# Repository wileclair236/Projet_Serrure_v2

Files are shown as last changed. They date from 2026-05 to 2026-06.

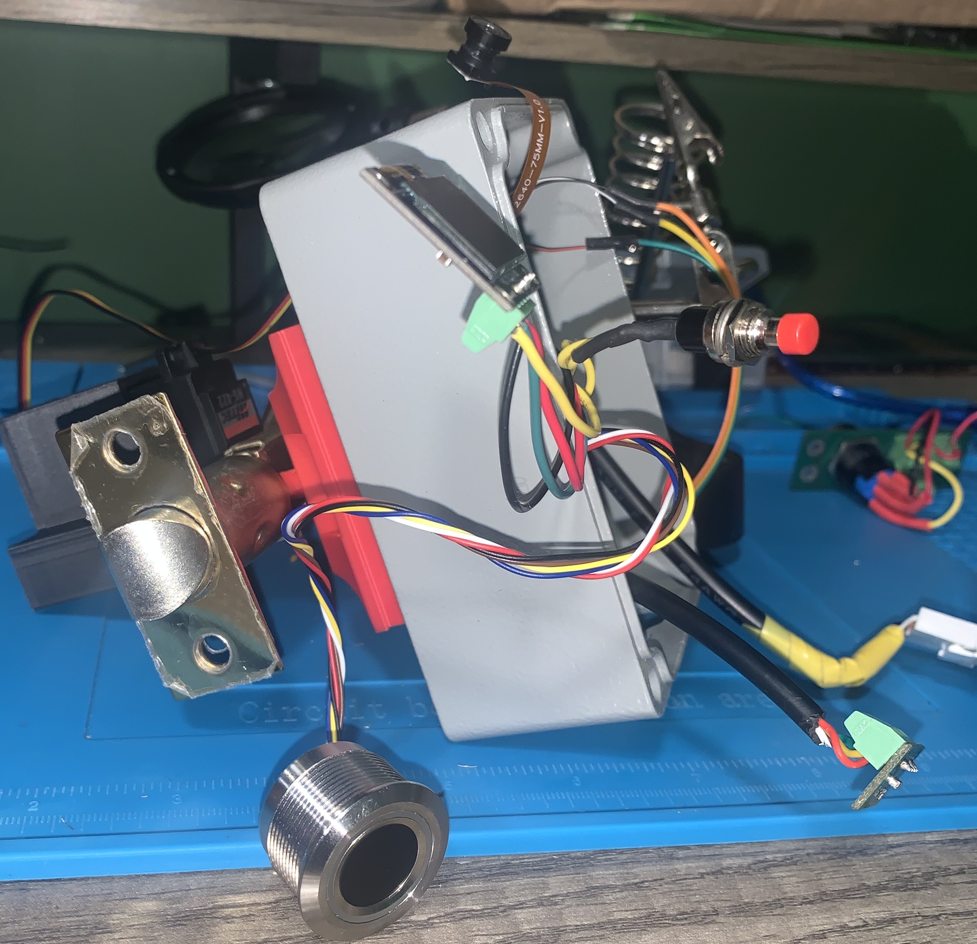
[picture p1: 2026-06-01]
Images/image site_web/IMG_6027.jpeg

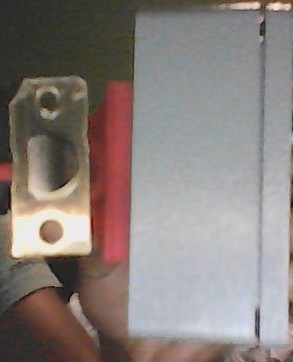
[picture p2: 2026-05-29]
Images/image site_web/photo serrure 2.jpg

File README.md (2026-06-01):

# Serrure Intelligente Connectée

## Description

Ce projet consiste en la conception et la réalisation d'une serrure intelligente connectée permettant le contrôle d'accès d'une porte à l'aide de plusieurs méthodes d'authentification. La serrure peut être commandée localement ou à distance via Home Assistant.

Le système est composé de plusieurs circuits imprimés (PCB) assurant la gestion des accès, les communications sans fil, l'acquisition d'images, le stockage des événements et le contrôle du mécanisme de verrouillage.

## Fonctionnalités

* Déverrouillage par carte RFID
* Déverrouillage par empreinte digitale
* Déverrouillage à distance via Home Assistant
* Déverrouillage mécanique par clé
* Notifications en temps réel
* Capture d'images lors des événements d'accès
* Journalisation des accès
* Gestion de plusieurs utilisateurs
* Contrôle d'un servomoteur pour le verrouillage et le déverrouillage
* Communication sans fil via Wi-Fi et MQTT

## Architecture du système

### PCB principal

Le PCB principal assure le contrôle complet de la serrure :

* Gestion des communications avec Home Assistant
* Gestion des utilisateurs autorisés
* Traitement des demandes d'accès
* Contrôle du servomoteur
* Acquisition et stockage des données
* Gestion des capteurs et périphériques

### PCB de la clé mécanique

Le PCB secondaire agit comme un interrupteur relié au PCB principal. Lorsqu'une clé est insérée puis tournée, il transmet un signal d'ouverture au contrôleur principal afin de permettre l'accès.

## Matériel utilisé

* ESP32-S3
* Lecteur RFID MFRC522
* Capteur d'empreintes digitales R503
* Caméra OV2640
* Écran OLED
* Servomoteur
* Carte microSD
* Capteur de proximité Vcnl36825t
* Batterie AA

## Logiciels utilisés

* PlatformIO
* Home Assistant
* MQTT
* Git
* KiCad

## Communication MQTT

Le système utilise MQTT pour transmettre les informations entre la serrure et Home Assistant.

## Sécurité

* Gestion des utilisateurs autorisés
* Journalisation des accès
* Authentification par plusieurs méthodes
* Surveillance des événements en temps réel
* Notifications automatiques vers Home Assistant

## Résultats

La serrure permet un contrôle d'accès sécurisé et connecté tout en conservant une solution de secours mécanique grâce à la clé physique. L'intégration avec Home Assistant offre une supervision en temps réel ainsi qu'une gestion centralisée des accès.

## Auteur

Wilkens Pinthière
Projet de conception d'une serrure intelligente connectée.

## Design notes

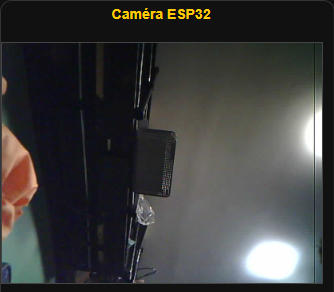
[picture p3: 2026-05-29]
Images/image site_web/stream.png

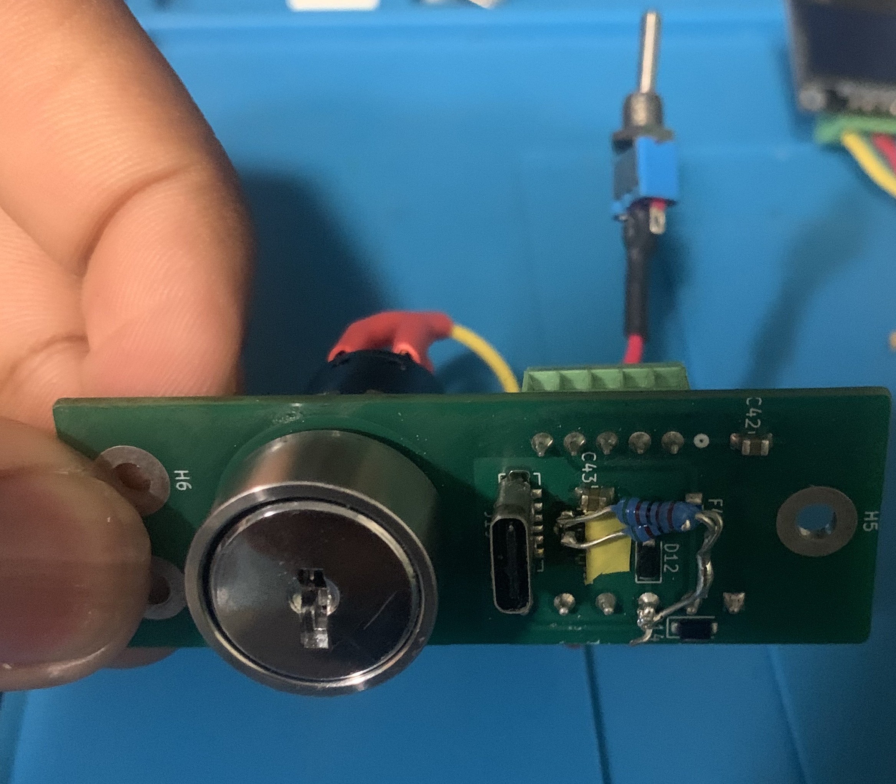
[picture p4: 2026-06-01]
Images/image site_web/Image PCB cle.jpeg

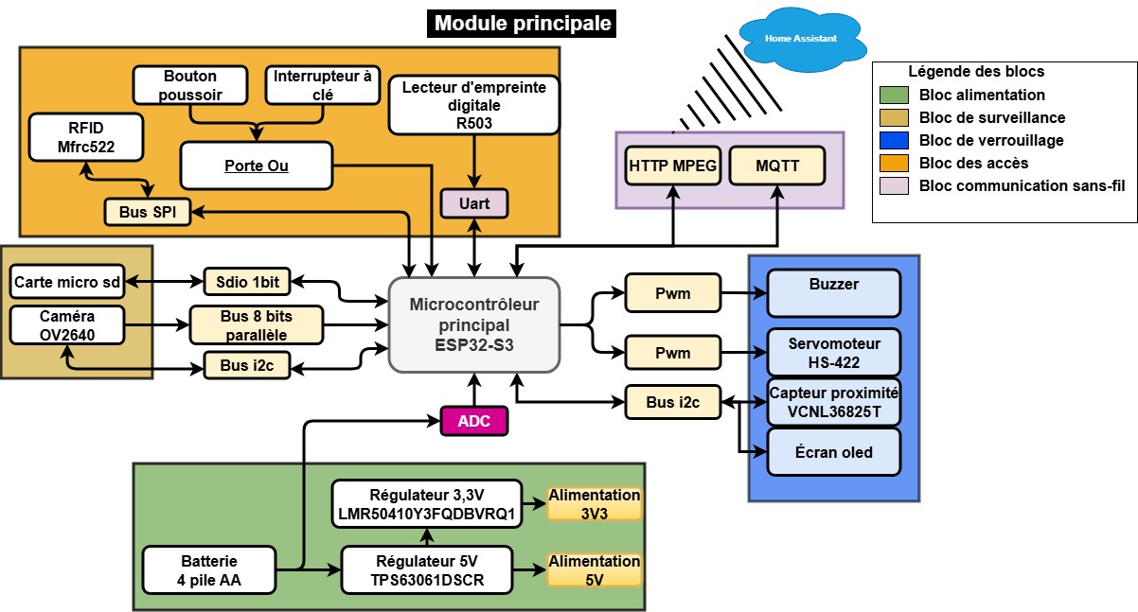
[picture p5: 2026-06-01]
Images/image site_web/Schema de principle.jpg

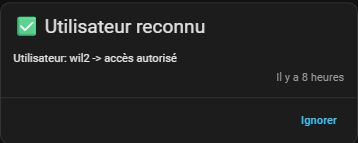
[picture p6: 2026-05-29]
Images/image site_web/HA_3.png

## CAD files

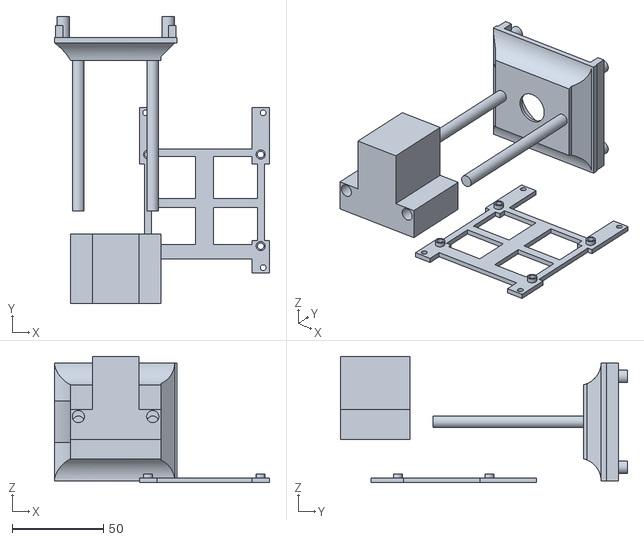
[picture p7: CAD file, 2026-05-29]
Fichier CAD/Fusion/impression 1.stl
118.1 x 157.5 x 69.2

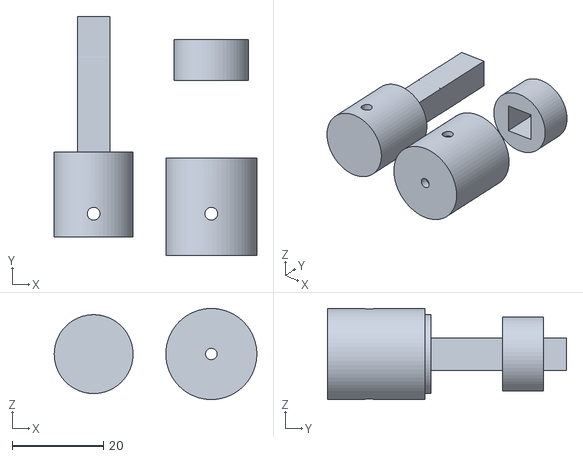
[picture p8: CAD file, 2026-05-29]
Fichier CAD/Fusion/impression 2.stl
44.4 x 52.3 x 19.9

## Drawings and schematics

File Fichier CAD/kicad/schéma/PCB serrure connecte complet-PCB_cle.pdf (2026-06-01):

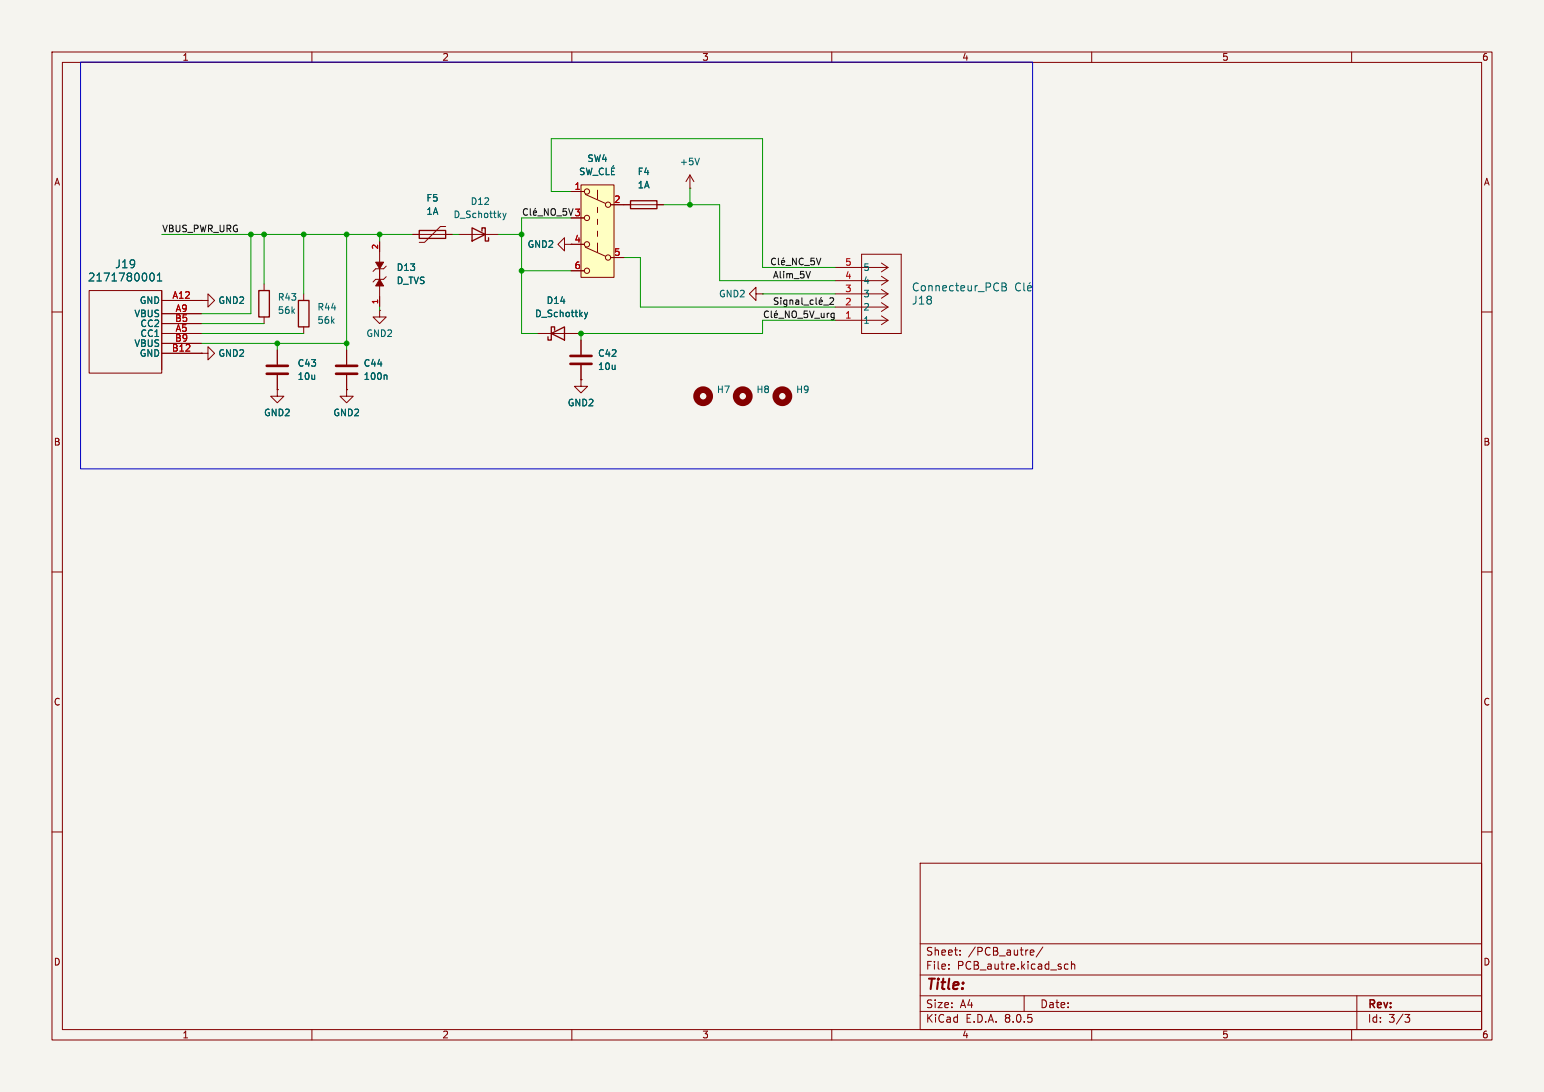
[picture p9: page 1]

Id: 3/3 Title: File: PCB_autre.kicad_sch Sheet: /PCB_autre/

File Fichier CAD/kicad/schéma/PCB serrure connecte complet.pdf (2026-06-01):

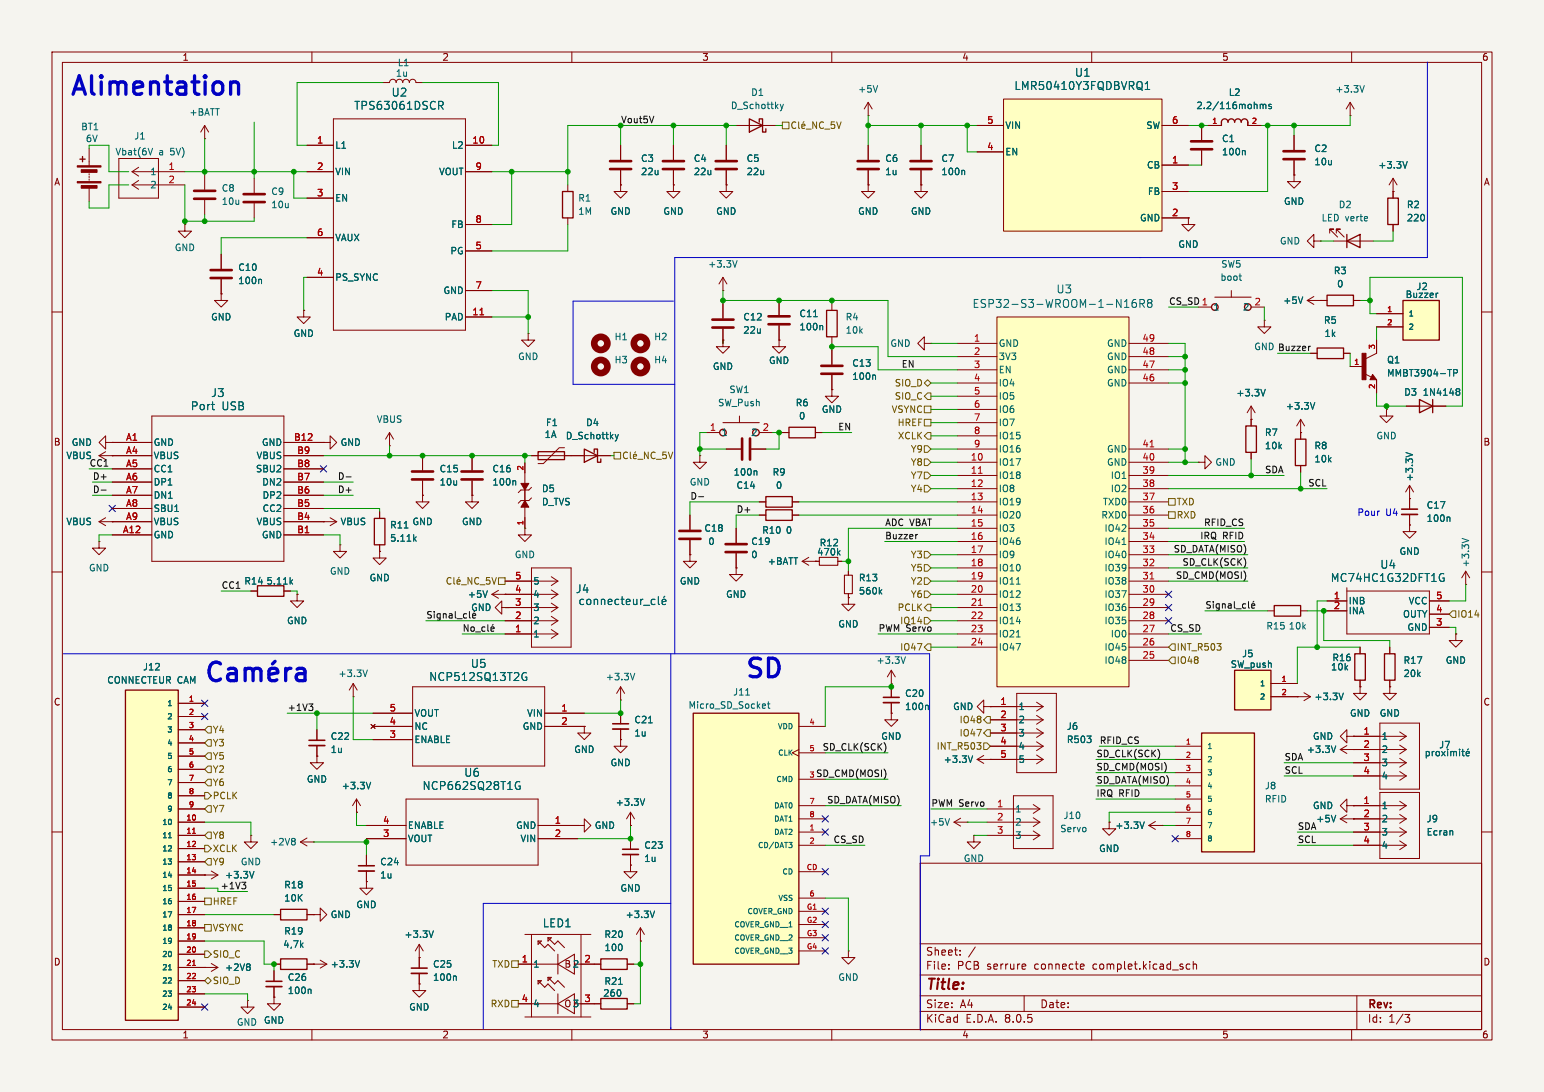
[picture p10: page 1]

Id: 1/3 Title: File: PCB serrure connecte complet.kicad_sch Sheet: /

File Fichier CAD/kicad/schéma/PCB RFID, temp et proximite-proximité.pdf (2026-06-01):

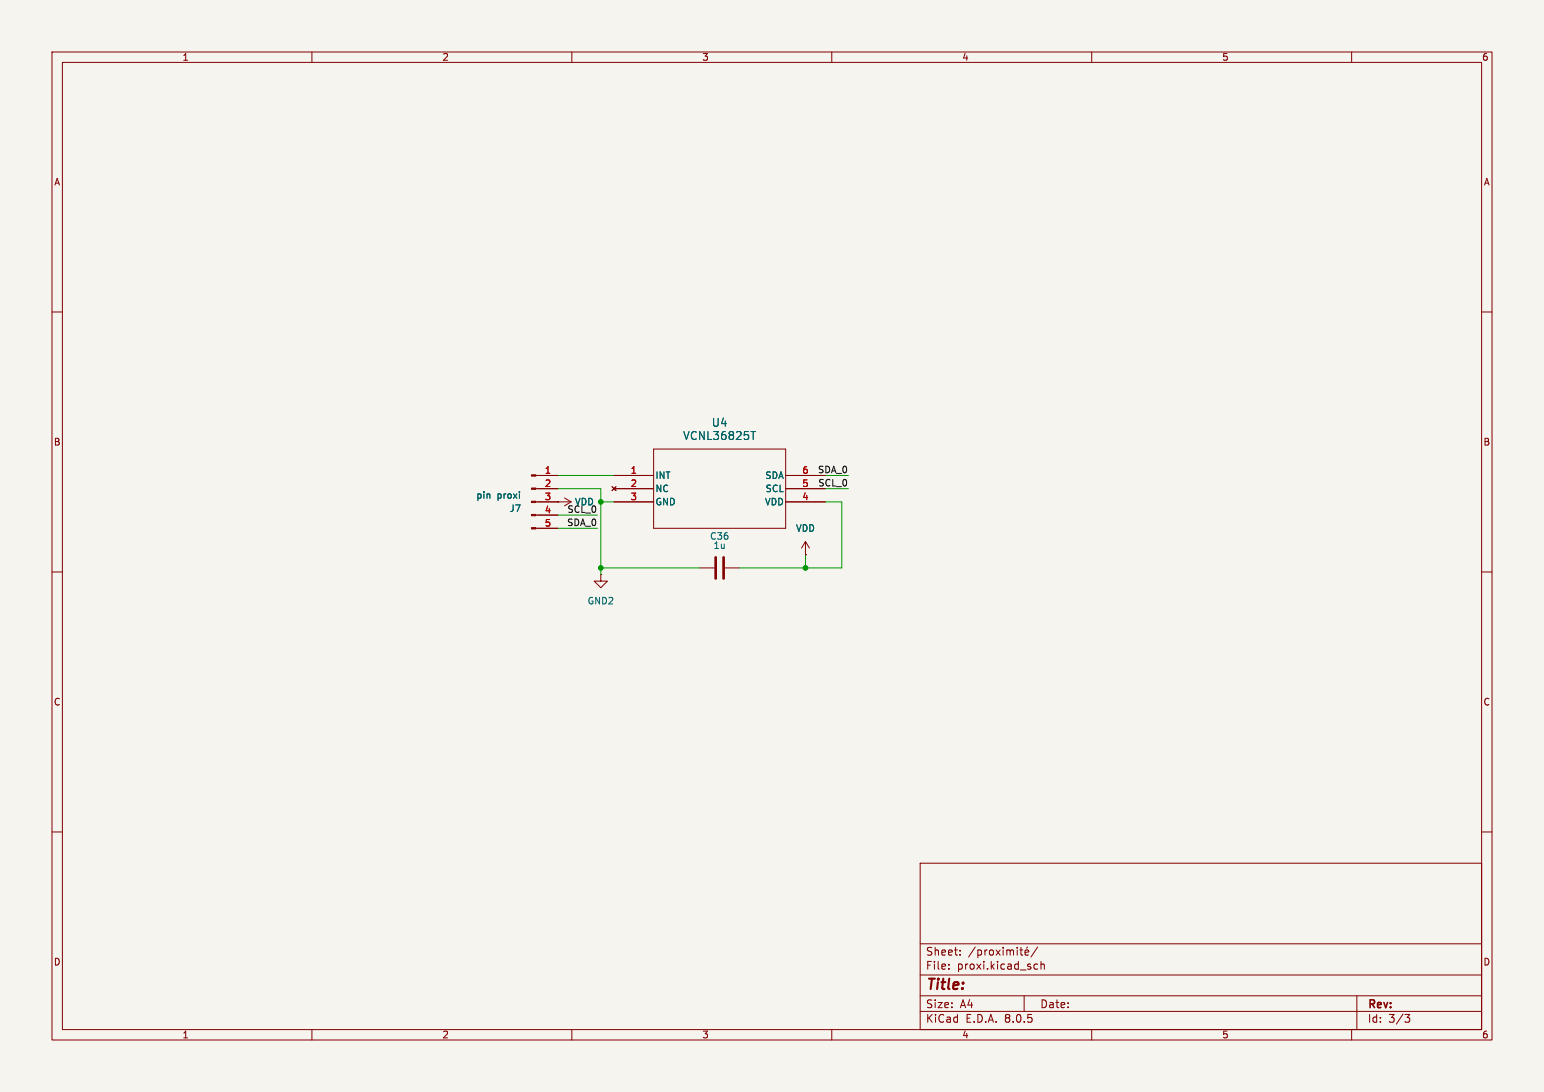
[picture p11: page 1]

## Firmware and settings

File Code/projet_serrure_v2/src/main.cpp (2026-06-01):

#include <Arduino.h>
#include <PubSubClient.h>
#include <WiFi.h>
#include "http_server.h"
#include "camera.h"
#include "img_converters.h"
#include "esp_http_server.h"
#include "freertos/semphr.h"
#include "wifi_config.h"
#include "Secret.h"
#include "mqtt.h"
#include "timer.h"
// #include "SD.h"
// #include "carte_sd.h"
#include <systeme_fichier.h>
#include <MFRC522.h>
#include <Users.h>
#include "fpm.h"
#include "fpm_logging.h"
#include "ArduinoJson.h"
#include "Proxi.h"
#include "Ecran.h"

//  FIX: #include doivent être au niveau global, jamais dans une fonction
#include "soc/soc.h"
#include "soc/rtc_cntl_reg.h"

#include "esp_attr.h"

enum etat_serrure
{
  Menu,
  Fonctionnement,
  Configuration,
  Sauvegarde
};
etat_serrure etat_actuel = Menu;

enum verrou
{
  barre_op,
  barre_cl,
  verrou_open,
  verrou_close
};
verrou etat_verrou = barre_cl;
#define MAX_USERS 10
RFIDTag users[MAX_USERS];

#define adc_pin 3
#define Commande_ouverture_porte_pin 14
/* ============ PWM servo PARAMS ============ */
#define PWM_servo_FREQ 50
#define PWM_servo_CHANNEL 0
#define PWM_servo_RESOLUTION 12
#define PWM_servo_PIN 21
uint32_t servo_duty_cycle = (1.5 * 4095) / 20.0;
int count_timer_porte_op;
/* ============ PWM vibreur PARAMS ============ */
#define PWM_vibreur_FREQ_autorise 4000
#define PWM_vibreur_FREQ_non_autorise 3000
#define PWM_vibreur_CHANNEL 2
#define PWM_vibreur_RESOLUTION 12
#define PWM_vibreur_PIN 46
uint32_t vibreur_duty_cycle = (125 * 4095) / 250;
/* ============ SPI PARAMS ============ */
#define RFID_SS_PIN 42
#define RST_PIN -1
#define SCK_PIN 39
#define MOSI_PIN 38
#define MISO_PIN 40
#define IRQ_RFID_PIN 41
/* ============ SD PARAMS ============ */
SystemeFichier systemeFichier;
File file;
/* ============ LECTEUR D'EMPREINTE DIGITAL PARAMS ============ */
#define TX_finger_PIN 47
#define RX_finger_PIN 48
int16_t fid2 = 0;
/* ============ PROXIMITY SENSOR PARAMS ============ */
#define SDA_PIN 1
#define SCL_PIN 2
/* ============ json document ============ */
JsonDocument doc;
JsonObject root = doc.to<JsonObject>();
/* ============ Oled ecran ============ */
using namespace oled;

/* ============ PARAMS ============ */
#define nbr_max_rep 50
#define division_rep 5
char payload[128];

//==========================================================//
void barre_ouverte(bool activation);
void barre_ferme(bool activation);
void deverrouiallge(bool activation);
bool porte_ouverture(void);
uint8_t etat_batterie(uint8_t niveau_batterie_precedent = 255);

RTC_DATA_ATTR char last_panic_hint[64] = {0};

void setup()
{
  Serial.begin(115200);
  delay(6000); // ← 6 secondes pour ouvrir le moniteur

  esp_reset_reason_t reason = esp_reset_reason();
  Serial.printf("=== RESET CAUSE: %d ===\n", reason);

  if (reason == ESP_RST_PANIC)
  {
    Serial.printf("=== DERNIER CHECKPOINT: %s ===\n", last_panic_hint);
  }

  // Reset
  strlcpy(last_panic_hint, "setup_start", sizeof(last_panic_hint));

  Serial.printf("Heap libre: %d bytes\n", ESP.getFreeHeap());
  Serial.printf("PSRAM libre: %d bytes\n", ESP.getFreePsram());

  delay(1000);
  Serial.println("Démarrage de l'ESP32...");
  delay(2000);

  // Initialisation GPIO
  pinMode(PWM_servo_PIN, OUTPUT);
  pinMode(PWM_vibreur_PIN, OUTPUT);
  pinMode(adc_pin, INPUT);
  pinMode(Commande_ouverture_porte_pin, INPUT);

  ledcSetup(PWM_servo_CHANNEL, PWM_servo_FREQ, PWM_servo_RESOLUTION);
  ledcAttachPin(PWM_servo_PIN, PWM_servo_CHANNEL);
  ledcWrite(PWM_servo_CHANNEL, servo_duty_cycle);

  ledcSetup(PWM_vibreur_CHANNEL, PWM_vibreur_FREQ_autorise, PWM_vibreur_RESOLUTION);
  ledcAttachPin(PWM_vibreur_PIN, PWM_vibreur_CHANNEL);
  ledcWrite(PWM_vibreur_CHANNEL, vibreur_duty_cycle);

  // --- Configuration du timer ---
  timer = timerBegin(0, 80, true);
  timerAttachInterrupt(timer, &onTimer, true);
  timerAlarmWrite(timer, 200000, true); // 200ms
  // Le timer est démarré dans le mode fonctionnement, après le menu de sélection
  // --- Fin configuration du timer ---

  setupRFID(SCK_PIN, MISO_PIN, MOSI_PIN, RFID_SS_PIN, IRQ_RFID_PIN, RST_PIN);
  delay(1000);

  systemeFichier.begin();
  systemeFichier.info();
  systemeFichier.contenu();
  camera_setup();
  delay(1000);

  Serial.println("Initialisation du lecteur d'empreinte digitale...");
  finger.Lecteur_Empreinte_Digital_Setup(RX_finger_PIN, TX_finger_PIN, 45);
  finger.ledConfigure(FPMLedControl::Allume, 0x40, FPMLedColour::Cyan);
  finger.ledOn();
  Serial.println("Vérification du capteur de l'empreinte digitale...");

  Setup_proxi(SDA_PIN, SCL_PIN);
  setup_ecran(SDA_PIN, SCL_PIN);
  delay(1000);
  vider_ecran();
  capture_picture();
  capture_picture();
  Serial.println("Setup terminé.");
}

void loop()
{
  if (etat_actuel == Menu)
  {
    // Rester dans le menu
  }
  else if (etat_actuel == Configuration)
  {
    etat_actuel = Configuration;
  }
  else if (etat_actuel == Sauvegarde)
  {
    etat_actuel = Sauvegarde;
  }
  else
  {
    etat_actuel = Fonctionnement;
    timerAlarmEnable(timer);
    finger.ledConfigure(FPMLedControl::Allume, 255, FPMLedColour::Violet, 10);
    finger.ledOn();
    Serial.println("Mode fonctionnement activé.");
  }

  switch (etat_actuel)
  {
  case Menu:
  {
    Serial.println("=== MENU ===");
    Serial.println("1. Passer en mode sauvegarde");
    Serial.println("2. Passer en mode configuration");
    Serial.println("Entrez votre choix (1 ou 2) :");

    int choice = 0;
    int Count_loop = 0;
    while (choice == 0)
    {
      if (Serial.available() > 0)
      {
        choice = Serial.parseInt();
        Serial.println("Choix reçu : " + String(choice));
        if (choice == 1)
          etat_actuel = Sauvegarde;
        else if (choice == 2)
          etat_actuel = Configuration;
      }
      delay(10);
      Count_loop++;
      if (digitalRead(Commande_ouverture_porte_pin) == HIGH)
      {
        Serial.println("Bouton pressé, passage en mode configuration.");
        choice = 2;
        etat_actuel = Configuration;
        break;
      }
      else if (Count_loop > 500) // 5 secondes à 10ms de delay
      {
        Serial.println("Aucun choix reçu, passage en mode sauvegarde.");
        choice = 1;
        etat_actuel = Sauvegarde;
        break;
      }
    }
  }
  break;

  case Fonctionnement:
  {
    static int i = 1;
    int nbr_repetitions = nbr_max_rep / division_rep; // = 10
    uint32_t tag_scanner;

    //  Variable de debug stack — affichage périodique seulement
    static uint32_t last_stack_print = 0;
    uint8_t pourcentage_batterie = 1;

    while (1)
    {
      if (millis() - last_stack_print > 5000)
      {
        Serial.printf("Stack libre: %d bytes\n", uxTaskGetStackHighWaterMark(NULL));
        last_stack_print = millis();
      }

      bool flag = false;
      // Lecture protégée du flag timer
      portENTER_CRITICAL(&timerMux);
      flag = timerFlag;
      portEXIT_CRITICAL(&timerMux);

      if (flag)
      {
        portENTER_CRITICAL(&timerMux);
        timerFlag = false;
        portEXIT_CRITICAL(&timerMux);

        // Maintenir MQTT actif
        client.loop();

        uint16_t FID_scan;
        bool commande_ouverture = digitalRead(Commande_ouverture_porte_pin);

        //  Snapshot de count avec section critique pour toutes les comparaisons
        portENTER_CRITICAL(&timerMux);
        int local_count = count;
        portEXIT_CRITICAL(&timerMux);

        if (local_count == (i * (nbr_repetitions - 1)))
        {
          Serial.println("Commande reçue via MQTT: " + message_mqtt);

          if ((topic_message == "Serrure/mode_verrou") && (message_mqtt == Verrou_OP || message_mqtt == "UNLOCK"))
          {
            barre_ouverte(1);
          }
          else if (commande_ouverture == HIGH)
          {
            Serial.println("Bouton d'ouverture de porte pressé.");
            deverrouiallge(1);
            drawOpenLock();
            finger.ledConfigure(FPMLedControl::Clignotement_Flash, 50, FPMLedColour::Vert, 40);
            finger.ledOn();
            snprintf(payload, sizeof(payload), "Porte ouverte via bouton ou clé.");
            Envoi_MQTT("Serrure/log", payload, false);
            while (!porte_ouverture())
            {
            }
            vider_ecran();
            finger.ledConfigure(FPMLedControl::Allume, 255, FPMLedColour::Violet, 10);
            finger.ledOff();
          }
          else if ((tag_scanner = Detection_TagsRFID_IRQ()) > 0)
          {
            for (size_t j = 0; j < users[0].getNumConfiguredUsers(); j++)
            {
              if ((tag_scanner == users[j].getID()) && (users[j].getStatus() == WHITELIST))
              {
                Serial.printf("Utilisateur: %s -> accès autorisé\n", users[j].getUserName().c_str());
                deverrouiallge(1);
                drawOpenLock();
                finger.ledConfigure(FPMLedControl::Clignotement_Flash, 50, FPMLedColour::Vert);
                finger.ledOn();
                snprintf(payload, sizeof(payload), "Utilisateur: %s -> accès autorisé", users[j].getUserName().c_str());
                Envoi_MQTT("Serrure/log", payload, false);
                snprintf(payload, sizeof(payload), "{\"title\":\"✅ Utilisateur reconnu\",\"message\":\"Utilisateur: %s -> accès autorisé\"}", users[j].getUserName().c_str());
                Envoi_MQTT("Serrure/notification", payload, true);
                while (!porte_ouverture())
                {
                }
                vider_ecran();
                finger.ledConfigure(FPMLedControl::Allume, 255, FPMLedColour::Violet, 10);
                finger.ledOff();
              }
              else if ((tag_scanner == users[j].getID()) && (users[j].getStatus() == BLACKLIST))
              {
                Envoi_MQTT("Serrure/mode_verrou", Verrouiallge, true);
                drawClosedLock();
                finger.ledConfigure(FPMLedControl::Clignotement_Flash, 50, FPMLedColour::Rouge, 10);
                finger.ledOn();
                ledcWriteTone(PWM_vibreur_CHANNEL, PWM_vibreur_FREQ_non_autorise);
                Serial.printf("Utilisateur: %s -> accès non autorisé\n", users[j].getUserName().c_str());
                //  Utiliser  (index courant) au lieu de FID_scan (non initialisé ici)
                snprintf(payload, sizeof(payload), "{\"title\":\"❌ Utilisateur non autorisé\",\"message\":\"Utilisateur: %s -> accès non autorisé\"}", users[j].getUserName().c_str());
                Envoi_MQTT("Serrure/notification", payload, false);
                deverrouiallge(1);
              }
              else
              {
                ledcWriteTone(PWM_vibreur_CHANNEL, PWM_vibreur_FREQ_non_autorise);
                drawClosedLock();
                finger.ledConfigure(FPMLedControl::Clignotement_Flash, 50, FPMLedColour::Rouge, 10);
                finger.ledOn();
                deverrouiallge(1);
              }
            }
          }
          else if (Finger_irqFlag == true)
          {
            if (finger.Recherche_empreinte_correspondante(FID_scan))
            {
              Finger_irqFlag = false;
              Serial.printf("Empreinte digitale scannée avec FID: %d\n", FID_scan);
              Serial.printf("Utilisateur trouvé : %s\n", users[FID_scan].getUserName().c_str());
              deverrouiallge(1);
              snprintf(payload, sizeof(payload), "Utilisateur: %s -> accès autorisé", users[FID_scan].getUserName().c_str());
              Envoi_MQTT("Serrure/log", payload, true);
              snprintf(payload, sizeof(payload), "{\"title\":\"✅ Utilisateur reconnu\",\"message\":\"Utilisateur: %s -> accès autorisé\"}", users[FID_scan].getUserName().c_str());
              Envoi_MQTT("Serrure/notification", payload, true);
              drawOpenLock();
              finger.ledConfigure(FPMLedControl::Clignotement_Flash, 50, FPMLedColour::Vert);
              finger.ledOn();
              while (!porte_ouverture())
              {
              }
              vider_ecran();
              finger.ledConfigure(FPMLedControl::Allume, 255, FPMLedColour::Violet, 10);
              finger.ledOff();
            }
            else
            {
              Finger_irqFlag = false;
              drawClosedLock();
              finger.ledConfigure(FPMLedControl::Clignotement_Flash, 50, FPMLedColour::Rouge, 10);
              finger.ledOn();
              ledcWriteTone(PWM_vibreur_CHANNEL, PWM_vibreur_FREQ_non_autorise);
              camera_fb_t* fb = esp_camera_fb_get();
              saveImageToSPIFFS(fb);
              Serial.println("Empreinte digitale non reconnue.");
              snprintf(payload, sizeof(payload), "Empreinte digitale non reconnue.");
              Envoi_MQTT("Serrure/log", payload, false);
              snprintf(payload, sizeof(payload), "{\"title\":\"🚨 tentative d'intrusion\",\"message\":\"Empreinte digitale non reconnue.\"}");
              Envoi_MQTT("Serrure/notification", payload, true);

              sendAllImagesToHA();
              esp_camera_fb_return(fb);
              deverrouiallge(1);
            }
          }
          else if ((topic_message == "Serrure/mode_verrou") && (message_mqtt == Verrou_Ouverture))
          {
            deverrouiallge(1);
            Envoi_MQTT("Serrure/log", "Porte ouverte via accès à distance.", false);
            drawOpenLock();
            while (!porte_ouverture())
            {
            }
          }
          else if ((topic_message == "Serrure/mode_verrou") && (message_mqtt == Verrou_CL || message_mqtt == "LOCK"))
          {
            barre_ferme(1);
          }
          else
          {

            Serial.println("Commande inconnue.");
            Serial.println("Message MQTT: " + topic_message + " -> " + message_mqtt);
            Envoi_MQTT("Serrure/mode_verrou", Verrou_CL, true);
          }

          // Envoi de l'heure via MQT
          if (local_count == (1 || 5 || 9 || 13 || 17 || 21 || 25 || 29 || 33 || 37)) // = toutes les 4 secondes (200ms * 20)
          {
            Serial.println("Envoi de l'heure actuelle via MQTT...");
            getLocalTime(&timeinfo);
            strftime(payload, sizeof(payload), "%d/%m/%Y %Hh%Mm%Ss", &timeinfo);
            Envoi_MQTT("Serrure/message_time/home_Assistant", payload, true);
          }

          // FIX: Utiliser local_count pour la comparaison (déjà snapshottée)
          if (local_count == 36)
          {
            pourcentage_batterie = etat_batterie(pourcentage_batterie);
            snprintf(payload, sizeof(payload), "{\"Pourcentage_Batterie\":%d}", etat_batterie(pourcentage_batterie));
            Envoi_MQTT("Serrure/capteur/Batterie", payload, true);
            snprintf(payload, sizeof(payload), "{\"Proximite\":%d}", readProximity());
            Envoi_MQTT("Serrure/capteur/proximite", payload, true);
          }

          i = (i < division_rep) ? i + 1 : 1;
        }

        //  FIX: Utiliser local_count pour la comparaison de dépassement
        if (local_count > nbr_max_rep)
        {
          Serial.printf("count: %d dépasse seuil, réinitialisation.\n", local_count);
          portENTER_CRITICAL(&timerMux);
          count = 0;
          portEXIT_CRITICAL(&timerMux);
          i = 1; // i est local à cette tâche, pas besoin de section critique
        }
      }

      delay(1);
    }
  }
  break;

  case Configuration:
  {
    wifi_setup("", "", 0xff, "");
    char dateStr_json[32];
    getLocalTime(&timeinfo);
    strftime(dateStr_json, sizeof(dateStr_json), "%d/%m/%Y %Hh%Mm%Ss", &timeinfo);
    root["date_creation"] = dateStr_json;

    JsonArray tableau_wifi = root.createNestedArray("Parametres_WiFi");
    Serial.println("Paramètres WiFi ajoutés au JSON.");
    Serial.printf("SSID: %s, Password: %s, Hostname: %s, Fuseau_Horaire: %d\n",
                  WifiConfig.ssid.c_str(), WifiConfig.password.c_str(),
                  WifiConfig.hostname.c_str(), WifiConfig.fuseau_Horaire);
    JsonObject wifi_json = tableau_wifi.createNestedObject();
    wifi_json["SSID"] = WifiConfig.ssid;
    wifi_json["Password"] = WifiConfig.password;
    root["Hostname"] = WifiConfig.hostname;
    root["Fuseau_Horaire"] = WifiConfig.fuseau_Horaire;

    initMQTT();
    JsonArray tableau_MQTT = root.createNestedArray("Parametres_MQTT");
    JsonObject mqtt_json = tableau_MQTT.createNestedObject();
    mqtt_json["Server"] = mqttServer;
    mqtt_json["Port"] = mqttPort;
    mqtt_json["User"] = mqttUser;
    mqtt_json["Password"] = mqttPassword;
    mqtt_json["ClientID"] = mqttClientID;
    mqtt_json["MaxPacketSize"] = mqttMaxPacket;

    finger.emptyDatabase();

    Serial.println("=== MODE CONFIGURATION ===");
    Serial.print("Combien de users RFID voulez-vous configurer ? (1 à " + String(MAX_USERS) + ") : ");

    // FIX: Ne pas réutiliser count (variable partagée avec l'ISR) pour autre chose
    // Utiliser une variable locale dédiée
    int nb_users_config = 0;
    while ((nb_users_config == 0) || (nb_users_config > MAX_USERS))
    {
      while (Serial.available() == 0)
      {
      }
      nb_users_config = Serial.parseInt();
      if (nb_users_config < 1 || nb_users_config > MAX_USERS)
      {
        Serial.println("Veuillez entrer un nombre entre 1 et " + String(MAX_USERS) + ".");
        nb_users_config = 0;
      }
      else
      {
        Serial.println(nb_users_config);
      }
    }

    delay(1000);
    Serial.println("Veuillez présenter user");

    for (int i = 0; i < nb_users_config; i++)
    {
      while (users[i].getID() == 0)
      {
        if (uint32_t tag_uid = Detection_TagsRFID_IRQ())
        {
          delay(100);
          finger.getFreeId(&fid2);
          Serial.printf("ID libre trouvé : %d\n", fid2);
          Serial.printf("Veuillez présenter l'empreinte digitale de l'utilisateur %d...\n", i);
          delay(1000);
          while (!finger.Ajout_empreinte_digitale(fid2))
          {
            delay(100);
          }
          users[i] = RFIDTag(tag_uid, fid2, readUserInputWithBackspace(), readStatus());
        }
        else
        {
          Serial.println("En attente de détection du tag RFID...");
        }
      }
      Serial.println("User configuré :");
      users[i].printInfo();
      snprintf(payload, sizeof(payload), "User configuré : %s", users[i].getUserName().c_str());
      Envoi_MQTT("Serrure/log", payload, false);
    }
    delay(1000);

    JsonArray arr = root.createNestedArray("users");
    for (int i = 0; i < users[0].getNumConfiguredUsers(); i++)
    {
      JsonObject users_json = arr.createNestedObject();
      users_json["uid"] = users[i].getID();
      users_json["fid"] = users[i].getIdFinger();
      users_json["name"] = users[i].getUserName();
      users_json["status"] = users[i].getStatus();
    }

    serializeJsonPretty(doc, file);
    if (systemeFichier.writeFile("/config.json", doc.as<String>().c_str()))
    {
      Serial.println("JSON écrit sur SPIFFS !");
      Serial.println("Contenu du JSON :");
      Serial.print(systemeFichier.readFile("/config.json"));
      Serial.println("");
      file.close();
    }
    else
    {
      Serial.println("Erreur ouverture fichier !");
    }
    delay(2000);
    startCameraServer();
    Envoi_MQTT("Serrure/log", "Setup serrure terminé", false);
    etat_actuel = Fonctionnement;
  }
  break;

  case Sauvegarde:
  {
    if (!loadSecretsFromSPIFFS("/config.json"))
    {
      Serial.println("Failed to load secrets from SPIFFS");
      etat_actuel = Configuration;
    }
    else
    {
      wifi_setup(ssid.c_str(), wifiPassword.c_str(), fuseau, hostname.c_str());
      initMQTT();
      for (int i = 0; i < userCount; i++)
      {
        users[i] = RFIDTag(users_DeJson[i].uid, users_DeJson[i].fid, users_DeJson[i].name, users_DeJson[i].status);
        Serial.printf("uid: %d, fid: %d, name: %s, status: %d\n",
                      users[i].getID(), users[i].getIdFinger(),
                      users[i].getUserName().c_str(), users[i].getStatus());
      }
      startCameraServer();
      Envoi_MQTT("Serrure/log", "Setup serrure terminé", false);
      etat_actuel = Fonctionnement;
    }
  }
  break; 
  default:
    Serial.println("État inconnu.");
    break;
  }
}

void barre_ouverte(bool activation)
{
  if (activation)
  {
    Envoi_MQTT("Serrure/mode_verrou", Verrou_OP, true);
    barre_ferme(0);
    etat_verrou = barre_op;
    Serial.println("Mode verrou: Barré Ouverte");
    finger.ledConfigure(FPMLedControl::Clignotement_Flash, 255, FPMLedColour::Vert);
    finger.ledOn();
    drawOpenLock();
    servo_duty_cycle = (1 * 4095) / 20.0;
    ledcWrite(PWM_servo_CHANNEL, servo_duty_cycle);
  }
}

void barre_ferme(bool activation)
{
  if (activation)
  {
    Envoi_MQTT("Serrure/mode_verrou", Verrou_CL, true);
    barre_ouverte(0);
    etat_verrou = barre_cl;
    Serial.println("Mode verrou: Barré Fermé");
    vider_ecran();
    finger.ledOff();
    servo_duty_cycle = (2 * 4095) / 20.0;
    ledcWrite(PWM_servo_CHANNEL, servo_duty_cycle);
  }
}

void deverrouiallge(bool activation)
{
  barre_ouverte(0);
  barre_ferme(0);
  Serial.println("Verrou mode: déverrouillage");
  finger.ledConfigure(FPMLedControl::Clignotement_Flash, 200, FPMLedColour::Violet, 5);
  finger.ledOff();
  ledcWriteTone(PWM_vibreur_CHANNEL, 0);
  // Tous les cas mènent à verrou_close — switch simplifié
  etat_verrou = verrou_close;
  servo_duty_cycle = (2 * 4095) / 20.0;
  ledcWrite(PWM_servo_CHANNEL, servo_duty_cycle);
}
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

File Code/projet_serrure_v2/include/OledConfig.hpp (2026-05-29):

/**
 * @file OledConfig.hpp
 * @brief Единая конфигурация библиотеки OLED SSD1315
 *
 * Все файлы библиотеки должны включать этот заголовок для получения
 * флага OLED_ENABLED, определения платформы и базовых настроек.
 *
 * Поддерживаемые платформы:
 * - Arduino (Wire) - автоопределение или -DOLED_PLATFORM_ARDUINO=1
 * - STM32 HAL      - -DOLED_PLATFORM_STM32HAL=1
 * - ESP-IDF        - -DOLED_PLATFORM_ESPIDF=1 (будущее)
 */

#ifndef OLED_CONFIG_HPP
#define OLED_CONFIG_HPP

// === Флаг включения библиотеки ===
// Определяется в build_flags: -DOLED_SSD1315_ENABLE=1
#if defined(OLED_SSD1315_ENABLE) && OLED_SSD1315_ENABLE
    #define OLED_ENABLED 1
#else
    #define OLED_ENABLED 0
#endif

// === Автоопределение платформы ===
// Приоритет: явный флаг > автодетекция

// Сбрасываем все платформы
#ifndef OLED_USE_ARDUINO
    #define OLED_USE_ARDUINO 0
#endif
#ifndef OLED_USE_STM32HAL
    #define OLED_USE_STM32HAL 0
#endif
// ESP-IDF поддержка (PLANNED - не реализовано)
#ifndef OLED_USE_ESPIDF
    #define OLED_USE_ESPIDF 0
#endif

// Явное указание платформы через build_flags
#if defined(OLED_PLATFORM_STM32HAL) && OLED_PLATFORM_STM32HAL
    #undef OLED_USE_STM32HAL
    #define OLED_USE_STM32HAL 1
#elif defined(OLED_PLATFORM_ESPIDF) && OLED_PLATFORM_ESPIDF
    #undef OLED_USE_ESPIDF
    #define OLED_USE_ESPIDF 1
#elif defined(OLED_PLATFORM_ARDUINO) && OLED_PLATFORM_ARDUINO
    #undef OLED_USE_ARDUINO
    #define OLED_USE_ARDUINO 1
#elif defined(ARDUINO)
    // Автодетекция Arduino
    #undef OLED_USE_ARDUINO
    #define OLED_USE_ARDUINO 1
#endif

// Проверка: хотя бы одна платформа должна быть определена
#if OLED_ENABLED && !OLED_USE_ARDUINO && !OLED_USE_STM32HAL && !OLED_USE_ESPIDF
    #error "OLED: No platform defined. Use -DOLED_PLATFORM_ARDUINO=1, -DOLED_PLATFORM_STM32HAL=1 or -DOLED_PLATFORM_ESPIDF=1"
#endif

// === Размеры буферов ===
#ifndef OLED_MAX_WIDTH
    #define OLED_MAX_WIDTH 128
#endif

#ifndef OLED_MAX_HEIGHT
    #define OLED_MAX_HEIGHT 64
#endif

// Максимальный размер framebuffer (128x64 / 8 = 1024 байт)
#define OLED_MAX_BUFFER_SIZE ((OLED_MAX_WIDTH * OLED_MAX_HEIGHT) / 8)

// Размер буфера для printf
#define OLED_PRINTF_BUFFER_SIZE 128

// === Wire buffer size ===
#ifndef OLED_WIRE_BUFFER_SIZE
    #define OLED_WIRE_BUFFER_SIZE 32
#endif

// === I2C Chunk Size ===
// STM32 HAL может передавать большие блоки, Arduino Wire ограничен 32 байтами
#if OLED_USE_STM32HAL
    #ifndef OLED_I2C_CHUNK_SIZE
        #define OLED_I2C_CHUNK_SIZE 128
    #endif
#else
    #ifndef OLED_I2C_CHUNK_SIZE
        #define OLED_I2C_CHUNK_SIZE 16
    #endif
#endif

#endif // OLED_CONFIG_HPP

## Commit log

2026-05-29 Ajout kicad et python
    [PCB RFID, temp et proximite.kicad_pcb, PCB RFID, temp et proximite.kicad_sch, PCB clé.kicad_pcb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]
2026-05-29 ajout video et stl
    [impression 1.stl, impression 2.stl]
2026-06-01 31/5/26 changement
    [PCB RFID, temp et proximite.kicad_pcb, PCB RFID, temp et proximite.kicad_sch, PCB clé.kicad_pcb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]
2026-06-01 image pcb
2026-06-01 image pcb2
